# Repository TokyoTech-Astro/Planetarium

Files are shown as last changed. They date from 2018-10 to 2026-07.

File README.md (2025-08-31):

# ディレクトリ構成

planetarium: 回路データ \
planetarium<西暦>: 各年にデプロイされたシステム \
memo: メモ(モーターの型番や星座とプレートナンバーの対応などの基本情報) 

# Bluetoothオーディオの使い方

## スピーカーとの接続方法

bluetoothctlを使う

[コマンド一覧](https://qiita.com/noraworld/items/55c0cb1eb52cf8dccc12)

```
$ bluetoothctl
```

デバイスの電源オン

```
# power on
# agent on
```

スキャン

```
# scan on
# scan off
```

ペアリング（スキャンで得たアドレスを指定する）

```
# pair 30:21:B0:70:83:33
# trust
```

接続

```
# connect 30:21:B0:70:83:33
```

## 音声の確認

```
aplay /usr/share/sounds/alsa/*
```

```
yt-dlp "https://www.youtube.com/watch?v=j7CDb610Bg0" -f bestaudio -o - | mplayer - -novideo
```

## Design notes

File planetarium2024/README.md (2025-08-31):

# RaspberryPiの基本情報

pi-controller(球外のpi)とpi-starsphere(球内のpi)の2枚を使用。

pi-controllerがオーディオ、モータ、恒星、ウェブサーバを担当。\
pi-starphereが星座、一等星を担当。

ホスト名
- pi-controller.local
- pi-starsphere.local

ユーザ名: pi \
パスワード: raspberry

## wifiへの自動接続
記憶が怪しいがnmcliで設定してた気がする。軽く調べて`../memo_wifi.txt`に申し訳程度にまとめておいたのでそちらを参照。

## bluetoothスピーカーへの自動接続
`apiServerAudio/autoconnector.sh`をcrontabで定期的に実行。\
＊ちょっと動作が怪しいので改良が必用。前繋がらなかったときは一回ペアリングを解除してから再接続したら解決した。

`../README.md`に情報あり。

# 各ディレクトリの説明

## httpServer
- スマホで操作するためのウェブページのサーバ
- Next.js + Material-UI(MUI)
- pm2を使いラズパイ本体起動時に自動起動
- `http://pi-controller.local:3000`でアクセス可能
- pi-controllerで動作

## apiServerAudio
- 音声を再生するAPIを提供
- bluetoothスピーカーへの自動接続スクリプトも含まれている
- pi-controllerで動作
- `pi-controller.local:8001`で動作

## apiServerMotor
- モータを駆動するAPIを提供
- pi-controllerで動作
- `pi-controller.local:8000`で動作

## apiServerLED
- LEDのを制御するAPIを提供
- pi-controllerとpi-starsphere(球内のpi)の両方で全く同じコードが実行されている
- `pi-starsphere.local:8002`、`pi-controller.local:8002`で動作

# デプロイ方法

## 環境変数
LEDのピンアサインや番組構成を変更する場合はこれらのファイルを書き換える。
- `leds.json`
- `k2023.json`
- `httpServer/.env`

各サブディレクトリ内にこれらへのシンボリックリンクが配置されていて、プログラムではシンボリックリンクを参照している。
- `apiServerLED/leds.json`と`httpServer/src/leds.json`は`leds.json`へのシンボリックリンクである。
- `httpServer/src/k2023.json`は`k2023.json`へのシンボリックリンクである。
- `httpServer/.env`のシンボリックリンクはなくプログラムから直接参照されている。

## サーバー自動起動設定

### httpServer
pm2を使って自動起動 \
See also: `memo_pm2.txt` `https://zenn.dev/dokokade/articles/452b5376f9e260`

### apiServerLED, apiServerMotor
systemdを使ってラズパイ起動時にソフトも自動起動

### apiServerAudio
apiServerLEDやapiServerMotorと同じくsystemdを使っているが--userオプションが必用。

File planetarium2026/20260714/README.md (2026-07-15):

# プラネ統合制御システム 20260714

統括・モーター制御とライト制御の両方にXIAO ESP32C3を使用します。

- `firmware/coordinator`: PCとのUART、モーター直接制御、ライト基板とのESP-NOW通信
- `firmware/light_controller`: 一等星、恒星、星座1～8の出力と状態返信
- `pc_ui`: Windows操作UIとEXE
- `docs`: 配線、設定、通信仕様

従来の独立したモーター制御マイコンは廃止し、統括マイコンへ統合しました。統括・モーター基板とライト基板の2台構成です。

ESP32C3はシングルコアのため、USB CDC・ESP-NOW・JSON処理はFreeRTOS通信タスクで動作します。モーターのCLOCK生成はハードウェアタイマー割り込みへ分離しているため、通信処理中もステップパルス生成を継続します。

## ビルド

各有効プロジェクトのフォルダーで次を実行します。

```powershell
pio run
```

書き込み前に、`firmware/coordinator/platformio.ini` のモーター1回転ステップ数、マイクロステップ数、回転方向を実機に合わせてください。

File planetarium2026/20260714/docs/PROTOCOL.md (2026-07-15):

# 通信仕様

## PC ⇔ 統括 (USB UART, 115200 bps, UTF-8 JSON Lines)

PCから送る主コマンド:

```json
{"cmd":"set","seq":12,"motor":{"angle":30.0,"speed":4.0},"light":{"first":true,"stars":true,"patterns":[true,false,false,false,false,false,false,false]}}
{"cmd":"config","esp_interval_ms":10000,"retry_timeout_ms":500,"max_retries":5}
{"cmd":"ping"}
{"cmd":"motor_cal","action":"jog_cw","speed":2.0,"value":0}
{"cmd":"motor_cal","action":"move_relative","speed":2.0,"value":-5.0}
{"cmd":"motor_cal","action":"set_zero","speed":0,"value":0}
{"cmd":"motor_cal","action":"set_angle","speed":0,"value":12.5}
{"cmd":"motor_cal","action":"exit","speed":0,"value":0}
```

統括からは `hello`, `status`, `event`, `pong` を返信します。`status` は各子機の通信状態、最終通信時刻、実際に反映された値を含みます。

`motor_cal` のactionは `jog_cw`, `jog_ccw`, `stop`, `move_relative`, `set_zero`, `set_angle`, `exit` です。校正コマンド受信後はモーターへの通常周期設定を一時停止し、`exit` で速度0として通常制御へ戻します。ライトへの周期送信は校正中も継続します。

## ESP-NOW

`protocol.h` のpacked固定長構造体を使用します。全パケットにmagic、version、type、sequenceを持たせます。統括は設定変更時に即送信し、通常時も設定間隔ごとに再送します。子機ACKがタイムアウトした場合は最大5回再送し、その間を不安定、終了後を途絶と判定します。

モーター校正には `MOTOR_CAL` と `MotorCalPayload` を使用し、通常のモーターACKで校正後の論理角度と速度を返信します。

固定MAC（ローカル管理アドレス）:

- 統括: `02:50:4C:41:4E:01`
- ライト: `02:50:4C:41:4E:02`
- モーター: `02:50:4C:41:4E:03`

## 現行プロトコル（Version 3）

- `AckPayload.angleDeg` は目標角度ではなく、統括・モーターマイコンが管理している実機の現在角度です。通常時は `0.0°以上360.0°未満` に正規化され、UIの「目標角度」行にある「実機現在値」へ表示されます。
- 目標角度 `999` は時計回り、`-999` は反時計回りの連続回転コマンドです。どちらも物理角度ではありません。連続回転中もACKの `angleDeg` は現在角度を返します。
- `AckPayload.uptimeMs` は各マイコンの起動後経過時間です。
- モーター校正中のUART `status.actual.motor.speed` は符号付きです。正は時計回り、負は反時計回り、0は停止を示します（ESP-NOWの構造体形式は変更しません）。
- 校正中の動作種別はUART `status.actual.motor.motion` で通知します。値は `jog_cw`（時計回り連続回転）、`jog_ccw`（反時計回り連続回転）、`relative`（相対角度移動）、`stopped`（停止）です。
- `status.actual.motor.target_angle` は位置移動の論理目標角度（0°以上360°未満）です。UIは相対角度移動中にこの値を表示します。
- `LightPayload.heartbeatTimeoutMs` はライト制御基板が通信切断と判断する時間です。統括側はESP-NOW定期送信間隔からこの値を算出して送信します。
- `LightPayload.fade` は、音声再生中にタイムラインが自然進行して設定値が変化した場合だけ `1` になります。ライト基板は恒星・一等星・星座出力を約1.2秒でフェードします。手動操作、シーク、再接続、即時送信では `0` となり即時反映します。

## 緊急停止

- PCから `{"cmd":"emergency_stop"}` を受けると、統括・モーター基板は緊急停止状態をラッチします。
- モーターの連続回転、位置移動、校正ジョグを直ちに停止し、回転速度を0にします。
- 一等星、恒星、星座1～8をすべてOFFとしてライト基板へ即時送信します。
- 緊急停止中の通常設定およびモーター校正指令は拒否されます。
- `{"cmd":"emergency_stop_release"}` を受けるまで、UARTの定期設定やタイムライン指令では解除されません。
- `status.emergency_stop` で現在のラッチ状態をUIへ通知します。
- ライト制御基板は有効な `LIGHT_SET` の最終受信から `heartbeatTimeoutMs` を超えると切断状態とし、D6の状態LEDを高速点滅します。正常時はゆっくり点滅します。
- 構造体変更によりVersion 3と旧Versionには互換性がありません。統括・モーター側とライト側を同じ版へ書き換えてください。

Wi-Fiチャネルは1に固定しています。

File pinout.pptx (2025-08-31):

## RaspberryPi

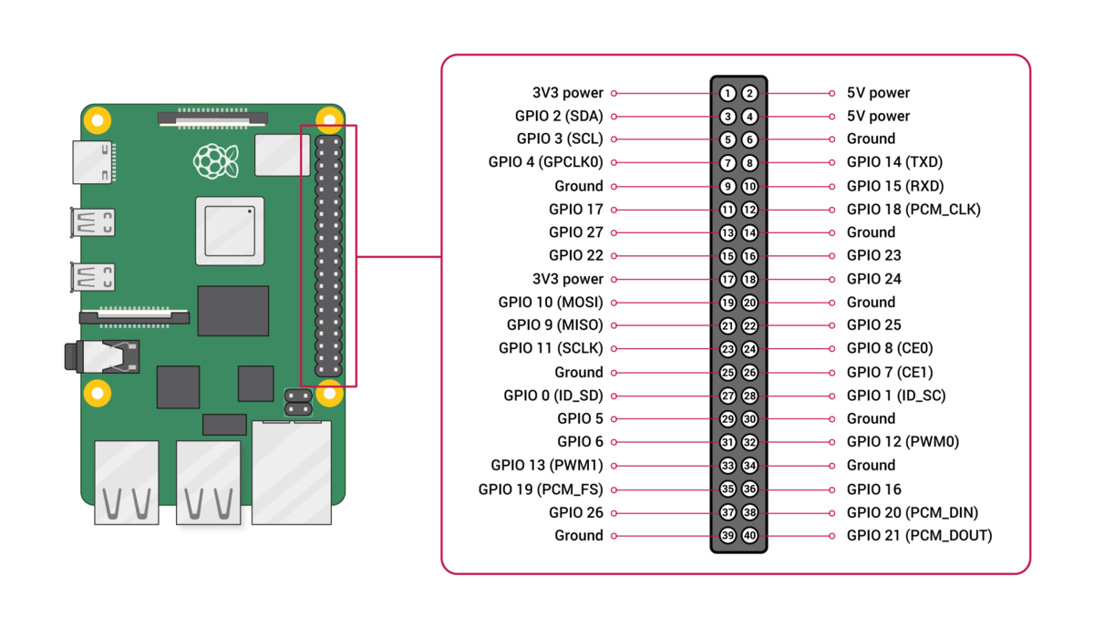
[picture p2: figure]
Raspberry PiのGPIOピン配置を確認する - BioErrorLog Tech Blog

緑文字＝モタドラ信号

| 1 | 2
| 3 | 4
| 5 | 6 | GND
Vdd | 7 | 8 | TX
GND | 9 | 10 | RX
sleep_ref | 11 | 12
cw_ccw | 13 | 14
clk | 15 | 16
| 17 | 18 | 一等星
恒星 | 19 | 20 | GND
| 21 | 22
| 23 | 24
| 25 | 26
| 27 | 28
| 29 | 30
| 31 | 32
| 33 | 34
| 35 | 36
| 37 | 38
| 39 | 40

Vdd

sleep/ref

cw_ccw

clk

星座

一等星

## 星座基板

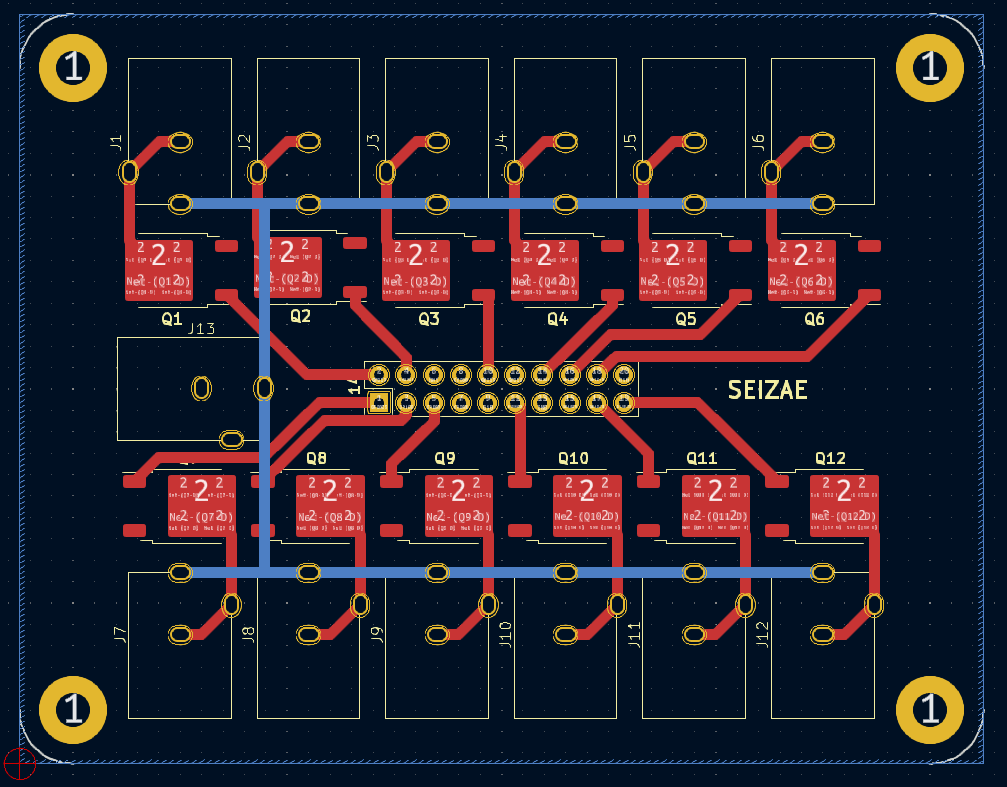
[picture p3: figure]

GPIO09

GPIO11

GPIO05

GPIO13

GPIO19

GPIO26

星座名 | GPIO (ラズパイ)
こぐま | 19
ぺがすす | 11
オリオン | 26
こいぬ | 13
さそり | 9
いて | 21

GPIO25

GPIO08

GPIO07

GPIO12

GPIO20

GPIO21

## モタドラ(SLA7078MPRT)

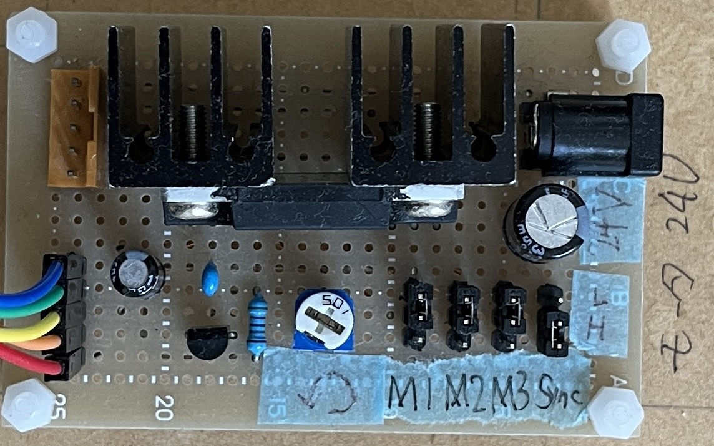
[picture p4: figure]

cw_ccw

clk

GND

sleep/ref

Vdd

参照電圧
(ccwに回転で上昇)

モードセレクト

IC: https://akizukidenshi.com/catalog/g/g108015/

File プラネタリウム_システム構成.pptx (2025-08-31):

## システム構成(2024)

RaspberryPi(pi-contoller)

球外

球内

RaspberryPi(pi-starsphere)

LED API

Webサーバ

LED API

ルータ

Audio API

モータ API

モータ基板
(24V駆動)

恒星基板
(24V駆動)

一等星基板
(5V駆動)

星座基板
(5V駆動)

※ラズパイから各APIへはhttpリクエストでアクセス

## システム構成(2025)

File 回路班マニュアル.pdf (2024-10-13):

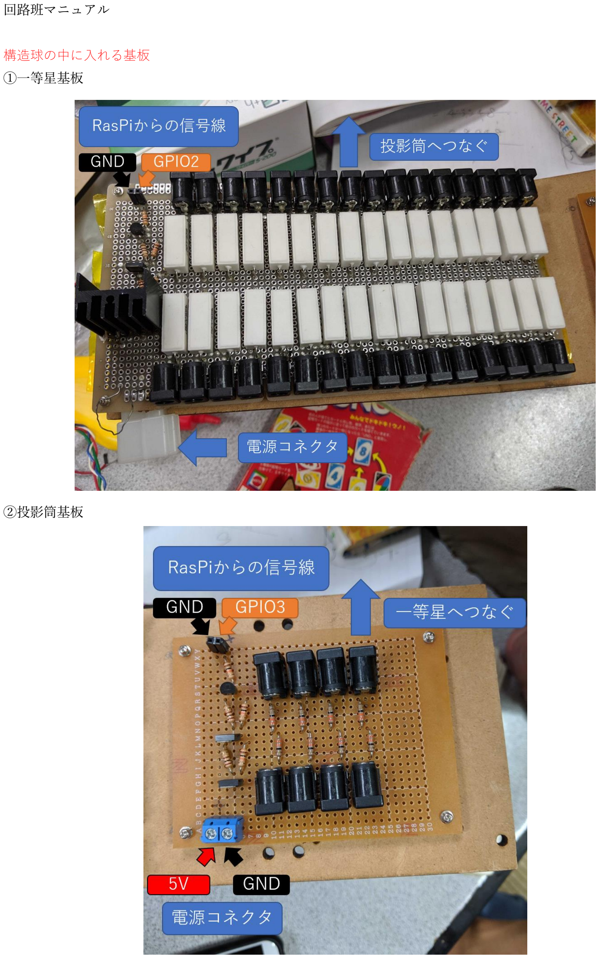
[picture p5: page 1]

回路班マニュアル

構造球の中に入れる基板
①一等星基板

②投影筒基板

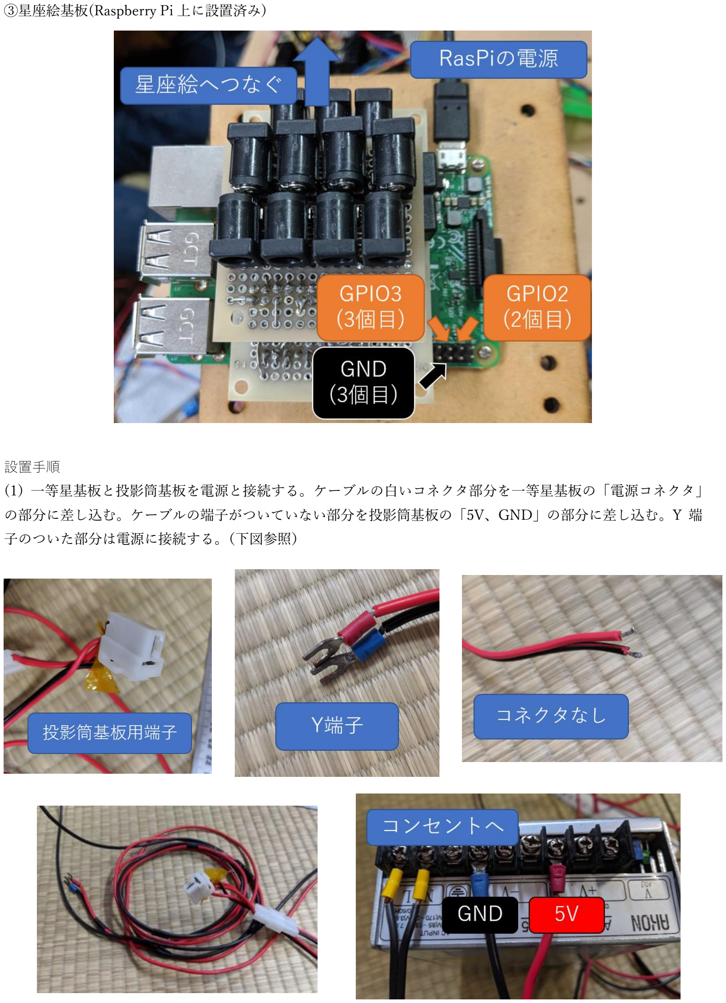
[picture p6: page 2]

③星座絵基板(Raspberry Pi 上に設置済み)

設置手順
(1) 一等星基板と投影筒基板を電源と接続する。ケーブルの白いコネクタ部分を一等星基板の「電源コネクタ」 の部分に差し込む。ケーブルの端子がついていない部分を投影筒基板の「5V、GND」の部分に差し込む。Y 端 子のついた部分は電源に接続する。（下図参照）

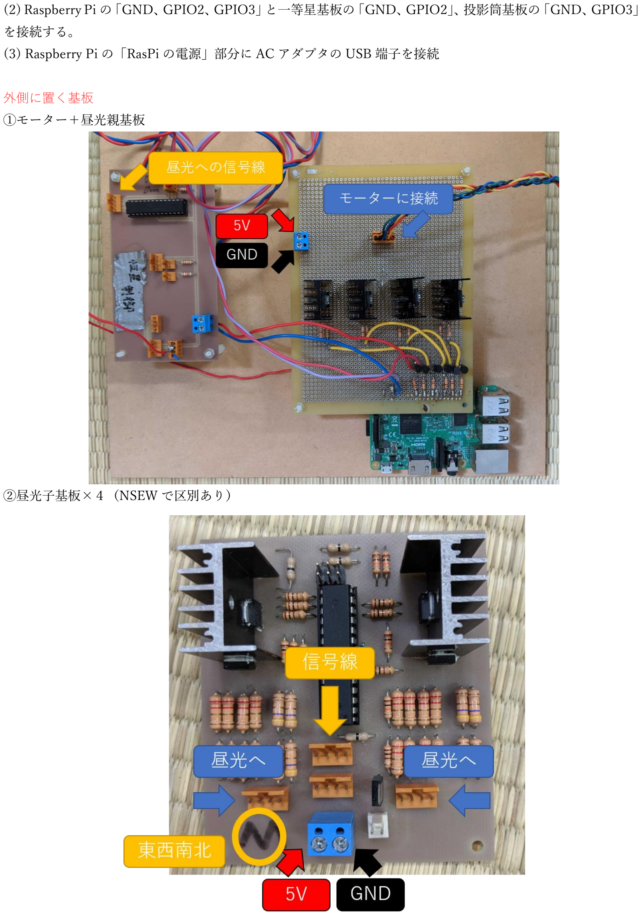
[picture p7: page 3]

(2) Raspberry Pi の「GND、GPIO2、GPIO3」と一等星基板の「GND、GPIO2」、投影筒基板の「GND、GPIO3」 を接続する。
(3) Raspberry Pi の「RasPi の電源」部分に AC アダプタの USB 端子を接続

外側に置く基板
①モーター＋昼光親基板

②昼光子基板×４（NSEW で区別あり）

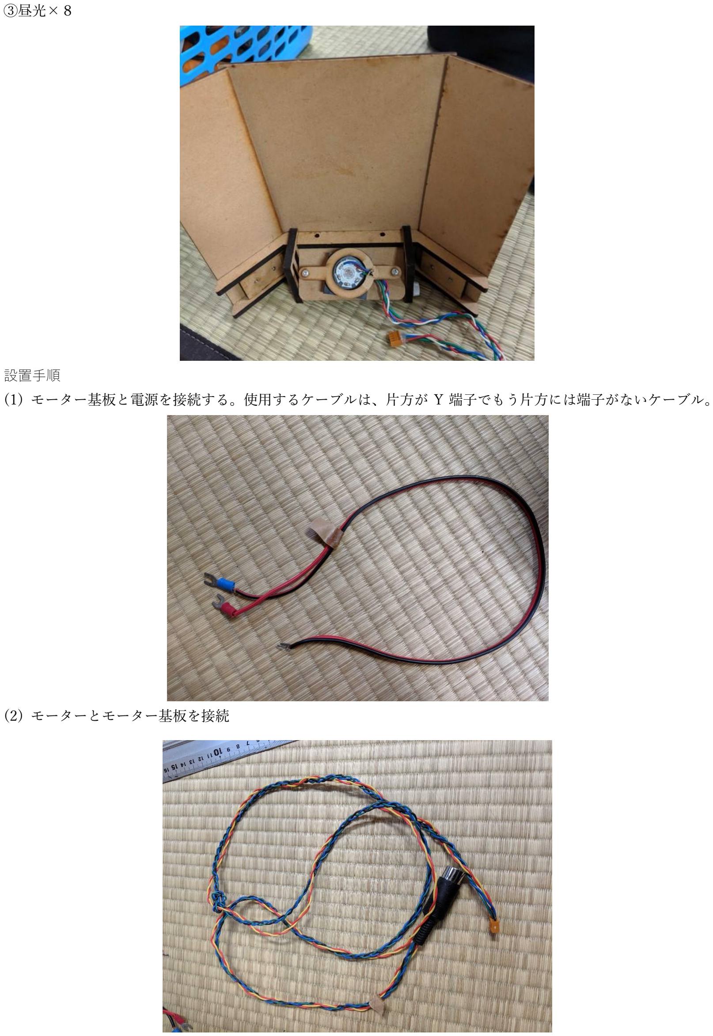
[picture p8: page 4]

③昼光×８

設置手順
(1) モーター基板と電源を接続する。使用するケーブルは、片方が Y 端子でもう片方には端子がないケーブル。
(2) モーターとモーター基板を接続

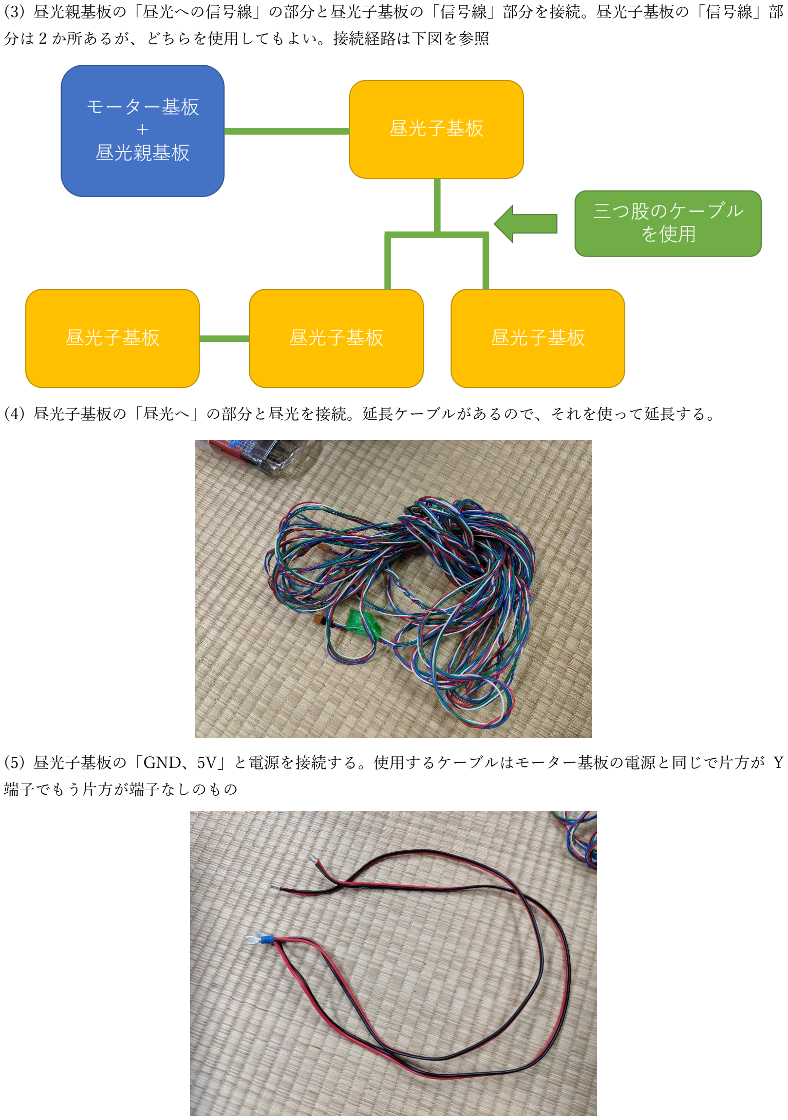
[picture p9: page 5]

(3) 昼光親基板の「昼光への信号線」の部分と昼光子基板の「信号線」部分を接続。昼光子基板の「信号線」部 分は 2 か所あるが、どちらを使用してもよい。接続経路は下図を参照
(4) 昼光子基板の「昼光へ」の部分と昼光を接続。延長ケーブルがあるので、それを使って延長する。
(5) 昼光子基板の「GND、5V」と電源を接続する。使用するケーブルはモーター基板の電源と同じで片方が Y 端子でもう片方が端子なしのもの

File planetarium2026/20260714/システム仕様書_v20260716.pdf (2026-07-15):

# プラネタリウム統合制御 システム仕様書

## PC UI・ステッピングモーター・ライト制御・通信・安全機能

対象システム

統括＋モーター基板：Seeed Studio XIAO ESP32C3 ライト制御基板：Seeed Studio XIAO ESP32C3 PC通信：USB CDC / UART 115200 bps 基板間通信：ESP-NOW（Wi-Fi Channel 1）

文書版：v20260716

対象フォルダ：planetarium2026 / 20260714

TokyoTech-Astro Planetarium Project

1. システム概要 | 全体構成と役割

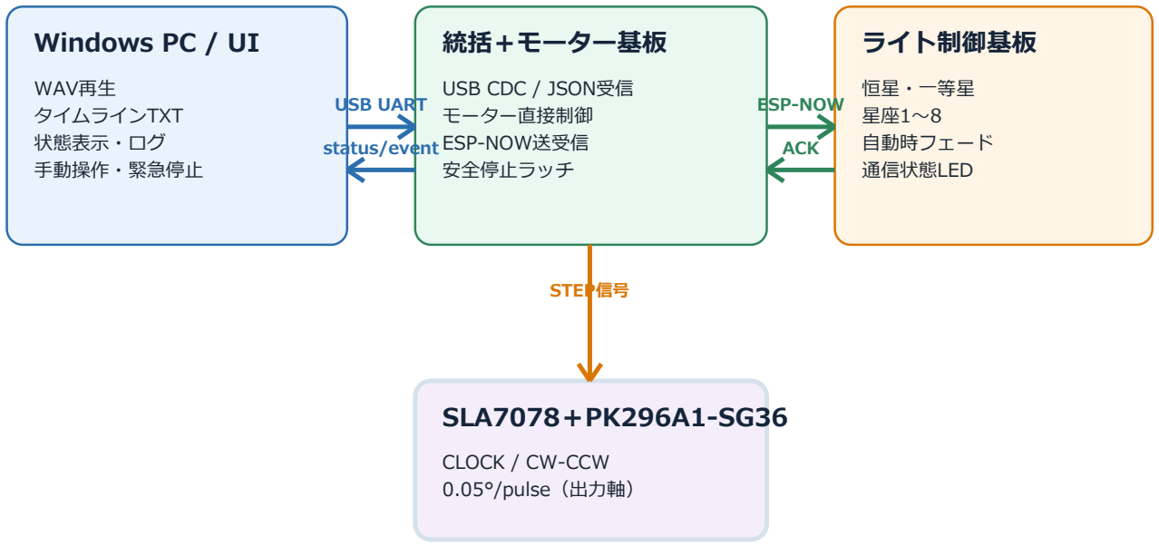
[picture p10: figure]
Windows PC / UI; WAV再生 タイムラインTXT 状態表示・ログ 手動操作・緊急停止; 統括＋モーター基板; USB CDC / JSON受信 モーター直接制御 ESP-NOW送受信 安全停止ラッチ; ライト制御基板; 恒星・一等星 星座1～8 自動時フェード 通信状態LED; USB UART; ESP-NOW; status/event; ACK; SLA7078＋PK296A1-SG36; CLOCK / CW-CCW 0.05°/pulse（出力軸）; STEP信号

プラネタリウム統合制御システム仕様書 v20260716 | 1

目的

音声ファイルの再生位置に同期して、ステッピングモーターの角度・速度と、恒星、一等星、星座1～8の点灯状態を自 動制御する。PC上のUIは状態監視、手動上書き、原点設定、緊急停止、ログ記録を担当する。

## 構成図

## 設計上の基本方針

モーターのSTEPパルス生成は40 kHzハードウェアタイマー割り込みへ分離し、通信処理の遅延から保護する。 PC通信が3秒途絶すると、統括基板単独でモーターを停止する。 再起動後は原点未設定とし、0°設定または現在角度設定まで通常移動を禁止する。 緊急停止は統括基板側でラッチし、明示的な解除まで通常指令と校正指令を拒否する。

2. PC UIとタイムライン制御 | 音声同期・操作・監視

## タイムラインの動作

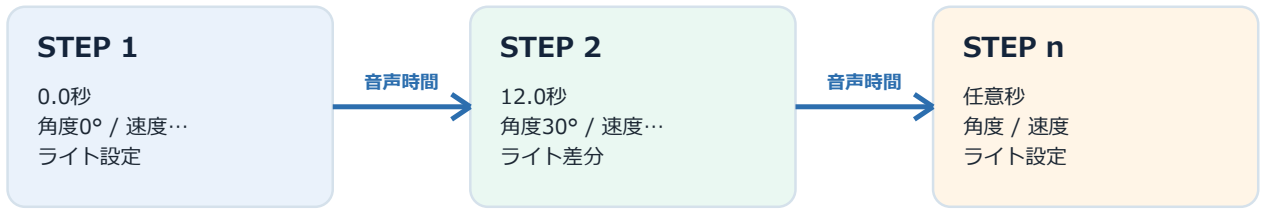
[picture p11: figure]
STEP 1; 0.0秒 角度0° / 速度… ライト設定; STEP 2; 12.0秒 角度30° / 速度… ライト差分; STEP n; 任意秒 角度 / 速度 ライト設定; 音声時間

再生位置がSTEP時刻を通過すると、そのSTEPの全設定値をUARTで即時送信する。設定に変化がない場合は送信を省略 し、変化がなくても既定10秒ごとに全設定を再送する。音楽再生中の自然なSTEP進行だけ、ライト指令の fade=true と なる。

## UIが提供する主な機能

区分 | 機能
音声 | WAV選択、再生・停止、シーク、倍率変更（ピッチ維持）、最初から再生
STEP | 全STEP一覧、現在STEP強調、前後移動、ダブルクリック移動、TXT編集
監視 | UART / ESP-NOW状態、最終通信、起動時間、要求値と実機値、ログ
手動 | 角度・速度・各ライトの上書き、現在値の即時送信
保守 | 0°設定、現在角度設定、ジョグ、相対角度移動
安全 | 緊急停止、赤色バナー、解除確認、通信途絶時の不明値表示

## 設定値の表示規則

ONは緑、OFFは赤。通信できないときの実機値には「?」を付け、確定値と区別する。 要求値と実機値が一致しない系統は、反映インジケータを赤く点滅させる。 手動上書き中の系統は背景色を変え、自動タイムラインより優先されていることを示す。

3. PC - 統括基板間通信 | USB CDC / UART / JSON Lines

## 物理・データ仕様

項目 | 仕様
接続 | XIAO ESP32C3 USB Type-C / USB CDC
通信速度 | 115200 bps
形式 | UTF-8 JSON、1メッセージ1行（改行終端）
定期送信 | 全設定：既定10秒、ping：1秒
安全監視 | 有効パケットを3秒受信しない場合、モーター強制停止

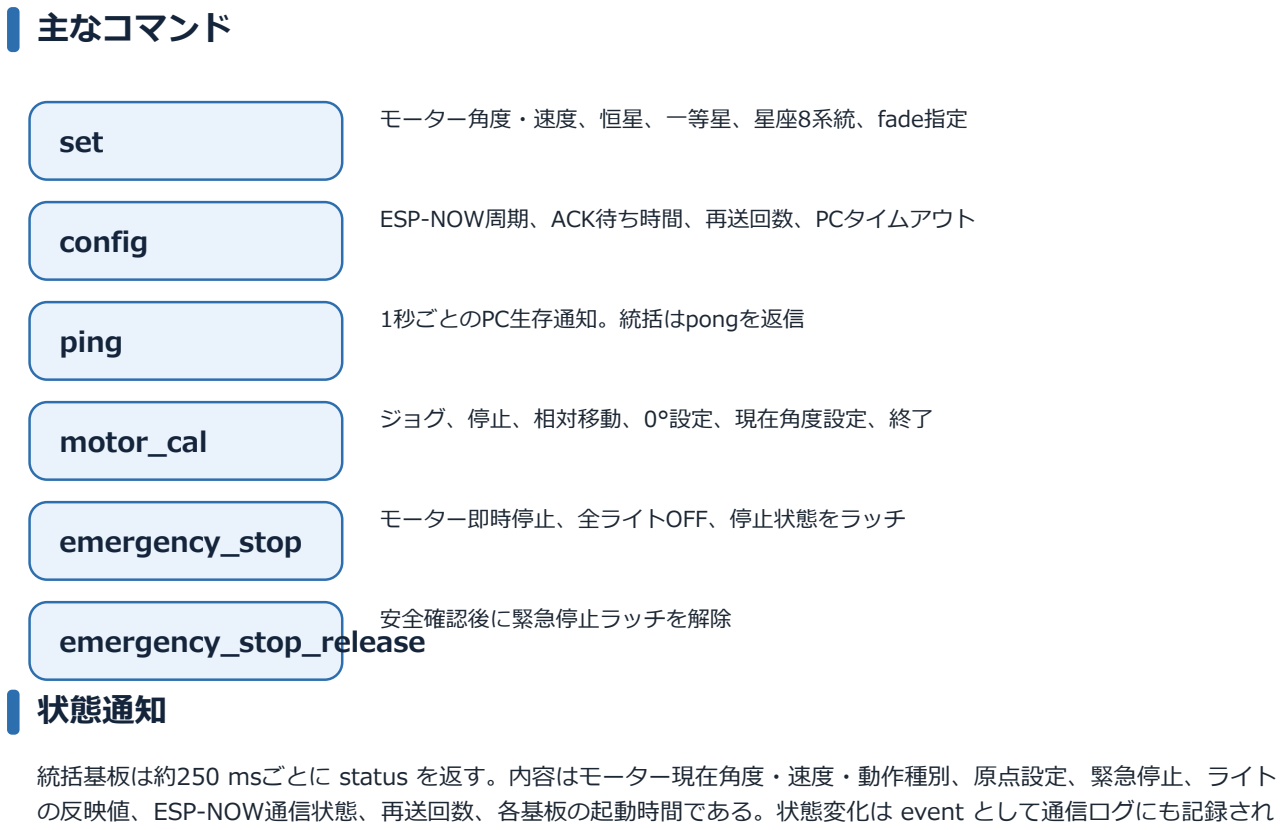
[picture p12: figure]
主なコマンド; set; モーター角度・速度、恒星、一等星、星座8系統、fade指定; config; ESP-NOW周期、ACK待ち時間、再送回数、PCタイムアウト; ping; 1秒ごとのPC生存通知。統括はpongを返信; motor_cal; ジョグ、停止、相対移動、0°設定、現在角度設定、終了; emergency_stop; モーター即時停止、全ライトOFF、停止状態をラッチ; emergency_stop_release; 安全確認後に緊急停止ラッチを解除; 状態通知; 統括基板は約250 msごとに status を返す。内容はモーター現在角度・速度・動作種別、原点設定、緊急停止、ライト の反映値、ESP-NOW通信状態、再送回数、各基板の起動時間である。状態変化は event として通信ログにも記録され

る。

4. ステッピングモーター制御 | 統括基板内蔵・タイマー分離

## 対象とパルス換算

PK296A1-SG36

2相ステッピングモーター
基本角1.8°、減速比36:1
出力軸：7,200 pulse/rev = 0.05°/pulse

制御上限

角度管理：0.0°以上360.0°未満
設定最大速度：300°/s
通常は実機に適した低速で運用

## 制御経路

ESP32C3はシングルコアだが、モーターCLOCK生成をハードウェアタイマー割り込みへ分離している。UART、JSON 、ESP-NOWの処理時間に左右されず、割り込みが継続してSTEPパルスを生成する。共有値の変更はクリティカル区間 で行う。

## 角度・原点・連続回転

通常角度は0°以上360°未満に正規化し、現在位置から最短方向で目標へ移動する。 目標角度999は時計回り、-999は反時計回りの連続回転コマンドであり、物理角度ではない。 再起動すると原点未設定となり、通常移動と±999を拒否する。ライト設定は先に復元できる。 0°設定または現在角度設定後に通常移動を許可する。校正画面の初期速度は0°/s。

## 主なGPIO

端子 | 用途
D0 | MO
D1/D8/D7 | M2 / M1 / M3
D2 | CLOCK
D3 | CW/CCW
D4 | FLAG
D5/D6 | SYNC / RESET
D9 | Driver Sleep
D10 | Status LED

5. 統括 - ライト基板間通信 | ESP-NOW / 固定MAC / ACK再送

## 無線設定

項目 | 統括＋モーター | ライト
固定MAC | 02:50:4C:41:4E:01 | 02:50:4C:41:4E:02
Wi-Fi Channel | 1 | 1
暗号化 | なし | なし
プロトコル | Packed struct / Version 3 | Packed struct / Version 3

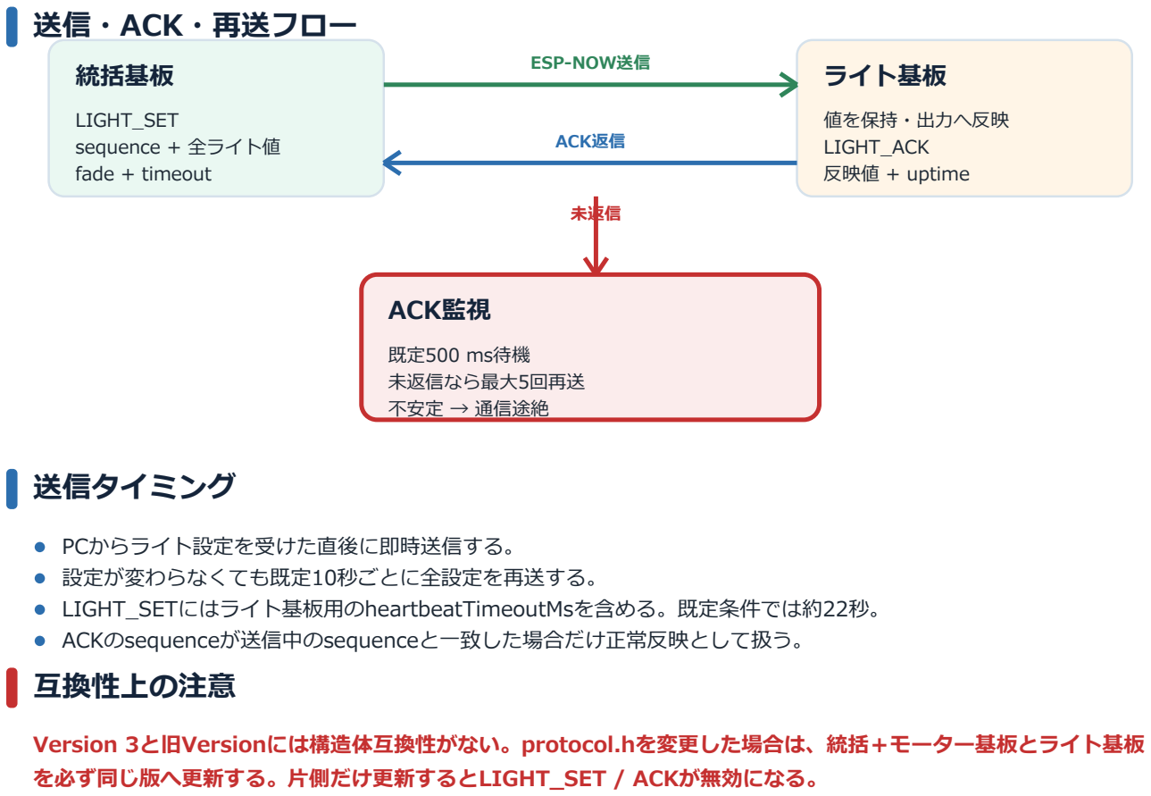
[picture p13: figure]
送信・ACK・再送フロー; 統括基板; LIGHT_SET sequence + 全ライト値 fade + timeout; ライト基板; 値を保持・出力へ反映 LIGHT_ACK 反映値 + uptime; ESP-NOW送信; ACK返信; ACK監視; 既定500 ms待機 未返信なら最大5回再送 不安定 → 通信途絶; 未返信; 送信タイミング; PCからライト設定を受けた直後に即時送信する。 設定が変わらなくても既定10秒ごとに全設定を再送する。 LIGHT_SETにはライト基板用のheartbeatTimeoutMsを含める。既定条件では約22秒。 ACKのsequenceが送信中のsequenceと一致した場合だけ正常反映として扱う。 互換性上の注意; Version 3と旧Versionには構造体互換性がない。protocol.hを変更した場合は、統括＋モーター基板とライト基板; を必ず同じ版へ更新する。片側だけ更新するとLIGHT_SET / ACKが無効になる。

## 出力割当

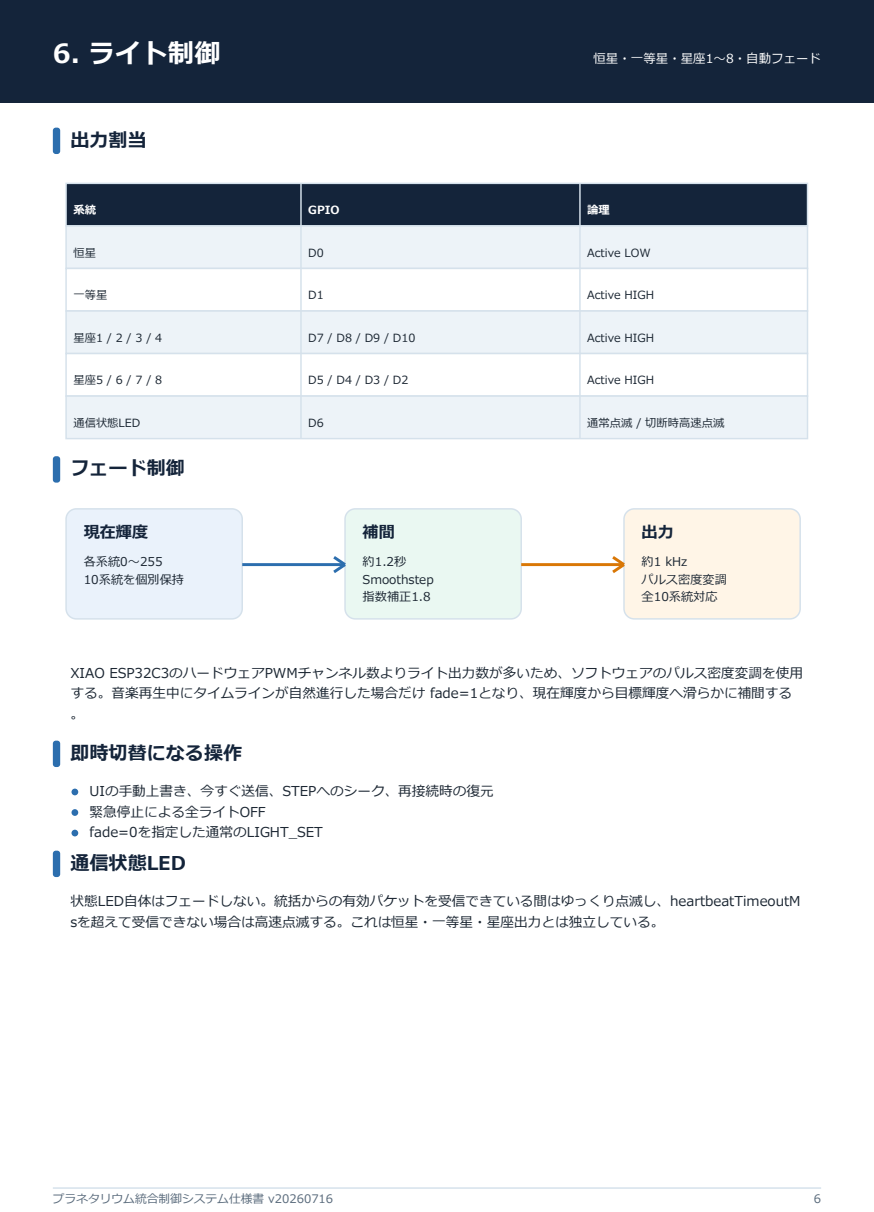
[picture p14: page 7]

XIAO ESP32C3のハードウェアPWMチャンネル数よりライト出力数が多いため、ソフトウェアのパルス密度変調を使用
する。音楽再生中にタイムラインが自然進行した場合だけ fade=1となり、現在輝度から目標輝度へ滑らかに補間する

状態LED自体はフェードしない。統括からの有効パケットを受信できている間はゆっくり点滅し、heartbeatTimeoutM
sを超えて受信できない場合は高速点滅する。これは恒星・一等星・星座出力とは独立している。

7. 安全機能と状態遷移 | 再起動・通信途絶・緊急停止

## モーター許可状態

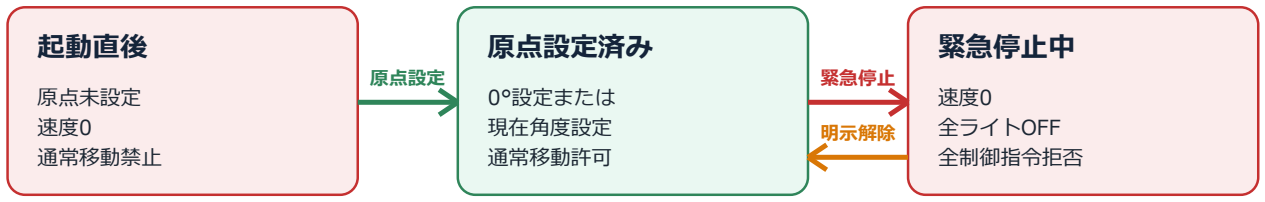
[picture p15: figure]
起動直後; 原点未設定 速度0 通常移動禁止; 原点設定済み; 0°設定または 現在角度設定 通常移動許可; 緊急停止中; 速度0 全ライトOFF 全制御指令拒否; 原点設定; 緊急停止; 明示解除

## PC通信途絶時

USB抜去、UIフリーズ、PC停止のいずれでも、統括基板が独立してモーター制御値をクリティカル区間内で停止値へ変 更する。PCが復帰した場合はeventを通知し、新しい有効指令から制御を再開する。

## 緊急停止フロー

### 1 UIの赤い緊急停止ボタンを押す

### 2 統括基板がラッチし、モーター即時停止・ライト全OFF

### 3 通常set、校正、タイムライン、定期送信を拒否

### 4 UIへ赤い緊急停止中バナーを表示

### 5 安全確認ダイアログ後、解除専用コマンドを送信

### 6 解除後に現在のUI設定を再送信

8. 起動・運用・保守 | 操作者と保守担当者の確認事項

## 標準起動手順

1 24Vを入れる前に、モーター基板のUSB Type-CをPCへ接続する。

### 2 モーター基板とライト基板へ24V電源を投入する。

### 3 UIを起動し、COMポートを選択してUART接続を押す。

### 4 PC－統括、統括－ライトの通信表示が正常であることを確認する。

### 5 指示設定TXTと対応するWAVを選択する。

### 6 Bluetoothスピーカーへ接続し、UIの出力先表示を確認する。

### 7 音声停止中にモーター0°位置を設定する。

### 8 自動変更ON、安全確認済みを確認して再生する。

## 保守時の重要事項

protocol.hを変更したときは、統括基板とライト基板の両方を同じVersionへ更新する。 モーター基板を書き換えた後、または再起動後は、必ず原点設定を行う。 異常音、振動、予期しない回転がある場合は緊急停止し、必要なら24Vを切る。 通常の操作者は操作者用フォルダだけを使用し、firmwareやpc_uiを変更しない。

## 関連ファイル

firmware/coordinator：統括＋モーター制御 firmware/light_controller：ライト制御 firmware/common/protocol.h：ESP-NOW共通構造体 pc_ui/app.py：Windows UI
docs/PROTOCOL.md：通信仕様
UIアプリの使用手順.txt：操作者向け詳細手順

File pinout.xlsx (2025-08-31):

 | 1 | 2 |  | 星座名 | pin num. (ラズパイ)
 | 3 | 4 |  | こぐま | 19
 | 5 | 6 | GND | ぺがすす | 11
Vdd | 7 | 8 | TX | オリオン | 26
GND | 9 | 10 | RX | こいぬ | 13
sleep_ref | 11 | 12 |  | さそり | 9
cw_ccw | 13 | 14 |  | いて | 21
clk | 15 | 16
 | 17 | 18 | 一等星
恒星 | 19 | 20 | GND
 | 21 | 22
 | 23 | 24
 | 25 | 26
 | 27 | 28
 | 29 | 30
 | 31 | 32
 | 33 | 34
 | 35 | 36
 | 37 | 38
 | 39 | 40

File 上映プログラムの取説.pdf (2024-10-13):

## 工大祭 2019 上映プログラムの取説

制作班チーフ 小池

1 | 事前準備
必要なソフト： | rlogin http://nanno.dip.jp/softlib/program/rlogin_x64.zip
netenum5 https://www.e-realize.com/netenum20191004.zip まずは上記の URL からダウンロードし、適宜 zip を展開しておきます。
2 | 上映の準備
2.1 | rlogin の設定
Wi-fi ルーター(Buffalo-G-203D)とラズベリーパイ 2 台を電源につなぎ起動します。PC をルーター に接続します。rlogin を起動し、左上のファイル→サーバーに接続→新規 と進みます。

ホスト名に pi-starsphere.local
ログインユーザー名に pi
パスワードに raspberry
と入力し保存します。

もう一度新規から画像の画面を開き、ホスト名を pi-controller.local に変え、ユーザー名・パスワードをその まま入力します。
入力ができたら、接続する機器を選んで接続します。こ

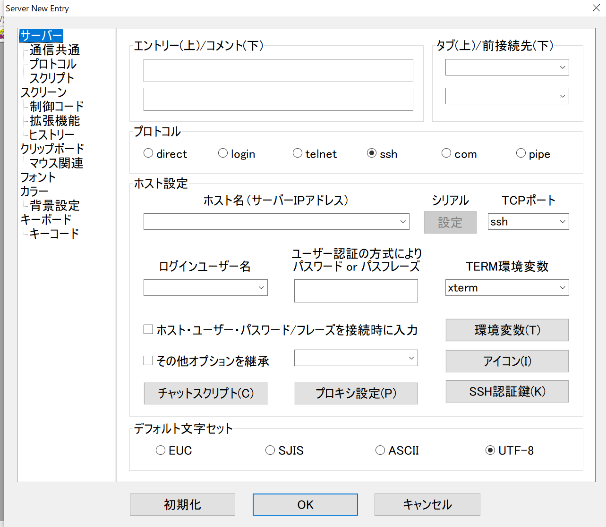
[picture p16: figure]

こで、エラーが発生した場合は 2.2 に進んでください。
2.2 2.1 でエラーがでたら NeteNum5 を起動します。左上の検索→検索設定と進み、設定はいじらず検索 します。ベンダー名に Raspberry Pi と出たら成功です(出なかったらもう一度やると出るようになる ことが多いです)
rlogin の設定画面で、ホスト名を～.local から NeteNum5 で表示された Ip アドレスに書き換えて再 度接続します。
(これでつながらなかったら終わり)
2.3 Rloin では 2 台のラズベリーパイをそれぞれつないでください。(rlogin を起動した画面で、ヘルプの 右下にある盾に分かれそうなボタンを押しましょう)
うまくいくとこんな感じになります。これでラズベリーパイを PC から動かせるようになりました (ssh 接続)

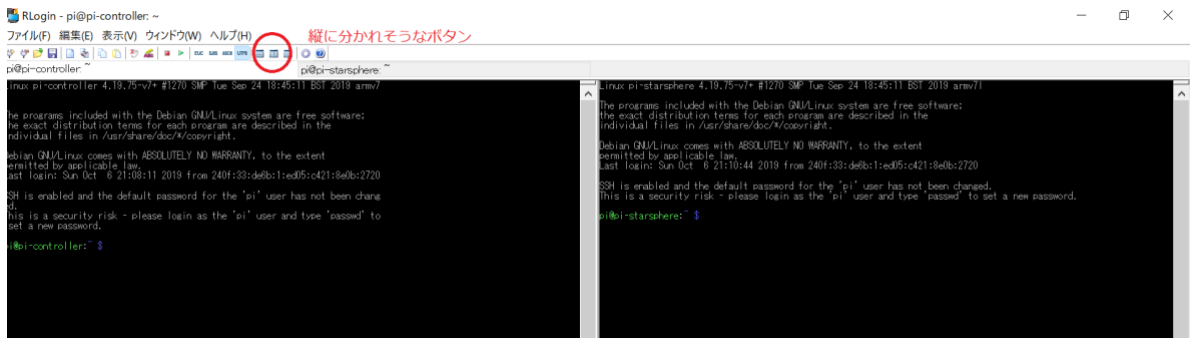
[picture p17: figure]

3 | ラズベリーパイの操作
3.1 | よく使うコマンドとか
cd (folder 名) | 指定したディレクトリに移動します。cd ..で一つ上に行けます。
ls | 現在のディレクトリ直下にあるファイルを一覧で見れます。
mkdir (名前) | 現在のディレクトリの直下に新しくフォルダを作ります。
nano (file 名) | ファイルを見て編集できます。
python3 (file 名)python のコードを実行します。
sh (file 名) | .sh のシェルスクリプトを実行します。
sudo reboot | 再起動します。
3.2 | 上映の実行の仕方
3.2.1 pi-starsphere(構造球側)で sh autorun.sh を実行します。 3.2.2 pi-controller(モーター側)で sh autorun.sh を実行します。 3.2.3 socket 通信が成功した場合はこんなのが出ます。

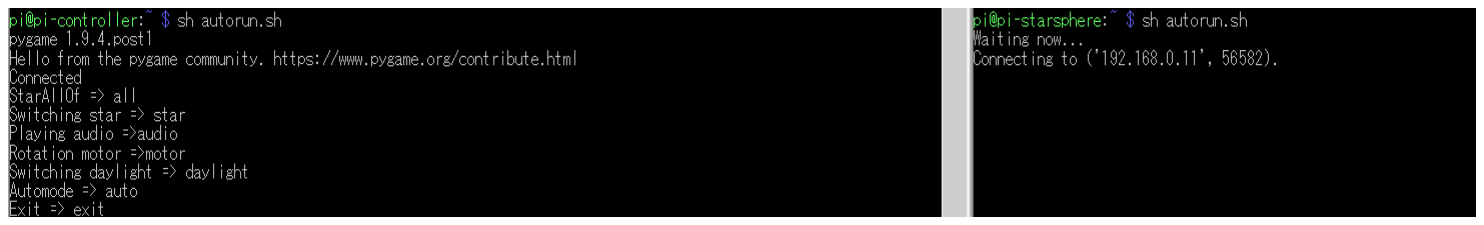
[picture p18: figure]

3.2.4 3 でエラーが出た場合は pi-starsphere のほうを再起動(sudo reboot)して、再度 pi-starsphere→ pi-controller の順で sh autorun.sh を実行します。
3.2.5 上映の時に使うのは Automode なので、pi-controller 側で auto と入力すると、上映が開始しま す。
3.2.6 終わると自動的に最初の画面に戻るので、次 auto と入力すれば ok です。
4 | バグったとき
4.1 | プログラムがやばそうな動きをしている
Ctrl + C で止めましょう。注意：必ず pi-controller のほうで行います。
4.2 モーターが回らない
3.2.3 の画像で、motor と入力します。その後 2 回数字が聞かれるので、0.04 と 200(または-200)と 入力すればモーターのテストができます。
4.3 星がつかない
3.2.3 の画像で star と入力します。そうすると on/off したい星と数字(または文字)の対応表が出るの で、目的の数字を入力します。この時、例えば 16 はこいぬ座の星座絵ですが、-16 とするとこいぬ 座を消すことができます。テストが終わったら exit と入力すれば先ほどの場面にもどります。 4.4 昼光がつかない
おなじみの方法で daylight と入力すると、on/off の選択肢が出るので好きなほうを入力してくださ い。
4.5 音が鳴らない
audio と入力してならなかったらスピーカーとかが原因です。
4.6 ラズパイが起動しない
終わりです、ごみを(ラズパイ)投げて本日の上映は終了です、と宣言しましょう。

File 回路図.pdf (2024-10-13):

## 天文る升

## r,xed stars)

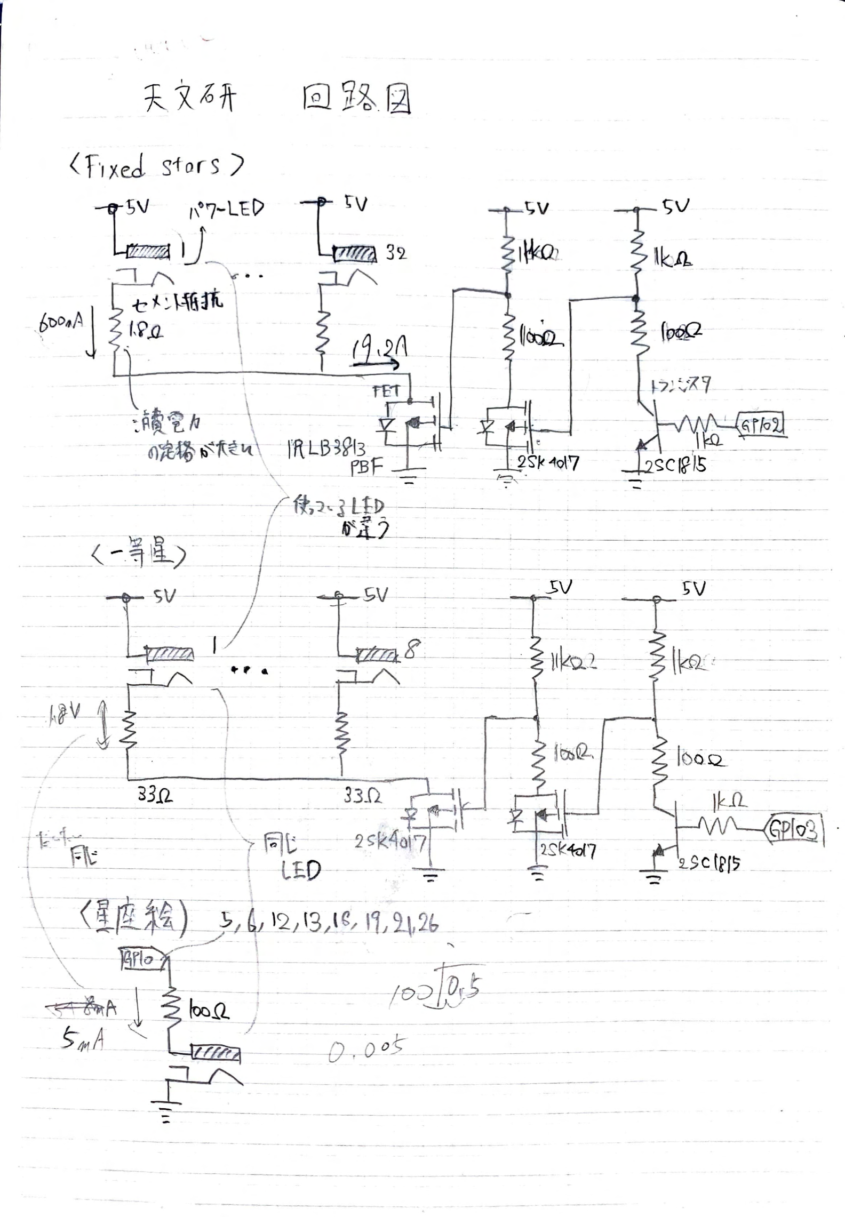
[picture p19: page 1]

- I•

# 1 7-L'ECl

ヘ
=-i_rヽ

~』砂；ン＼｀．．

## 回認旦

二鈴

佃和

心雌稔 ぶ紅＼1-t | !'ft.LB痢F.Bf _ | k-4o¥'/

I

r | ー | ・
1rs
ft1J ...l LfD | ――--――-
—- | ＿＿ ＿＿ーニ一ロ― ―
J | Tーロニ立~ ーニ _:_-~
｀口・・ r

_., . 一ヽ

## ―_ー印恥

lcQ | - ・一
、 | .
33立 | | | 3_Q
-、・,
; ・; ・ヤー—- -- • ー | ・ 極 | ~, 同 | 2s:-k401
-I -—~- -- -~- Lf. | --=:=--

（一

## c trr~ _ _

＼汀直釦三ぶ21訊 | 11,汎21, | ―

# 三三:~ {? , ° i;iと

三ゴ＼ — ---- -、一

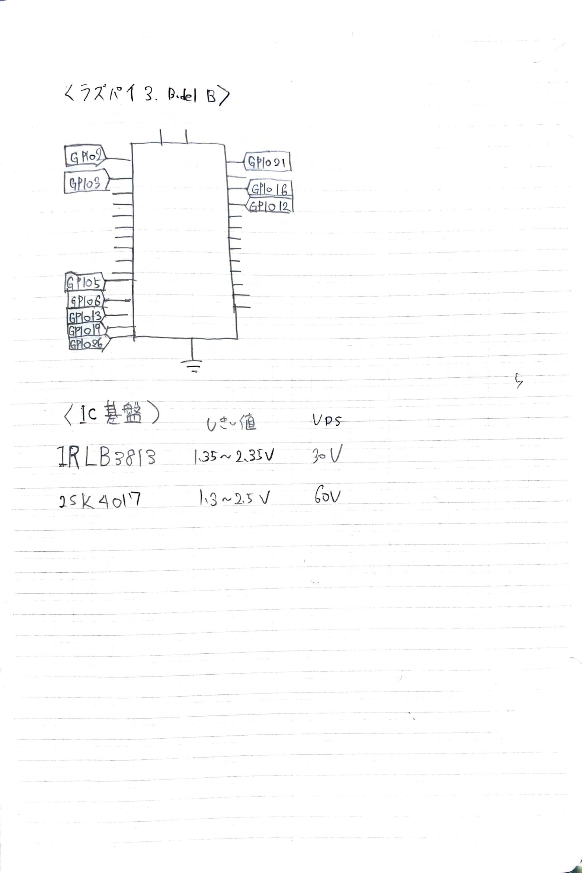
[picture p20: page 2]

くラズ（＼゜ 1'l(i、Jel
日、

←

## 甚磐〉 い!v〈直

- --― 仁 ―--

— V-P-5- -~- - ------ --- —
lRLB霜応 、3;-"" 、3S¥) ]。リ

_ 1~k L¥ o ¥'l ¥3 ~2S v I :>

I

人

## 応尤立

年）

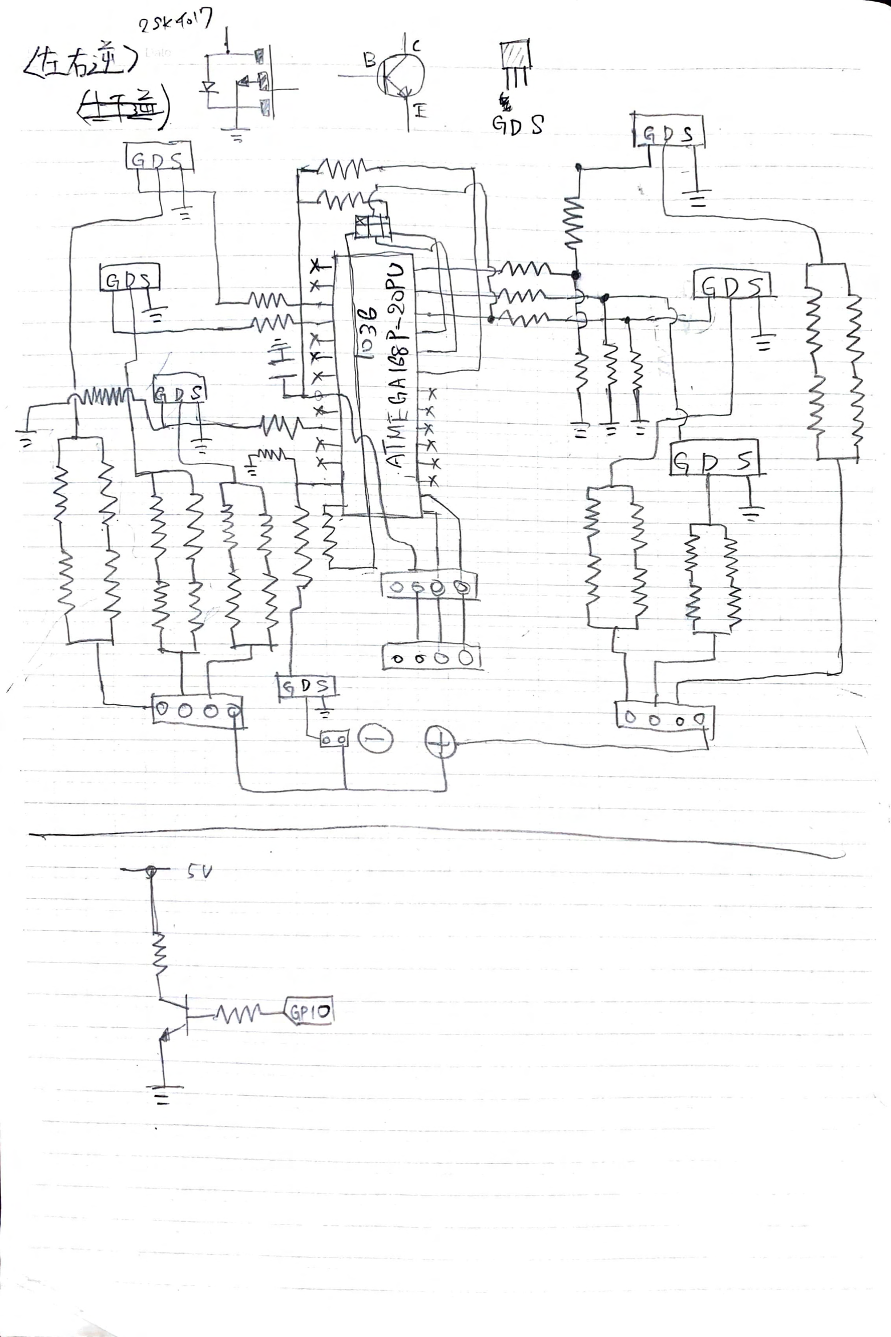
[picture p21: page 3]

s

開
ぷ

~:

／
‘ ＼、

r-v

ぃ憂

一

## （昼も芦的 ｀

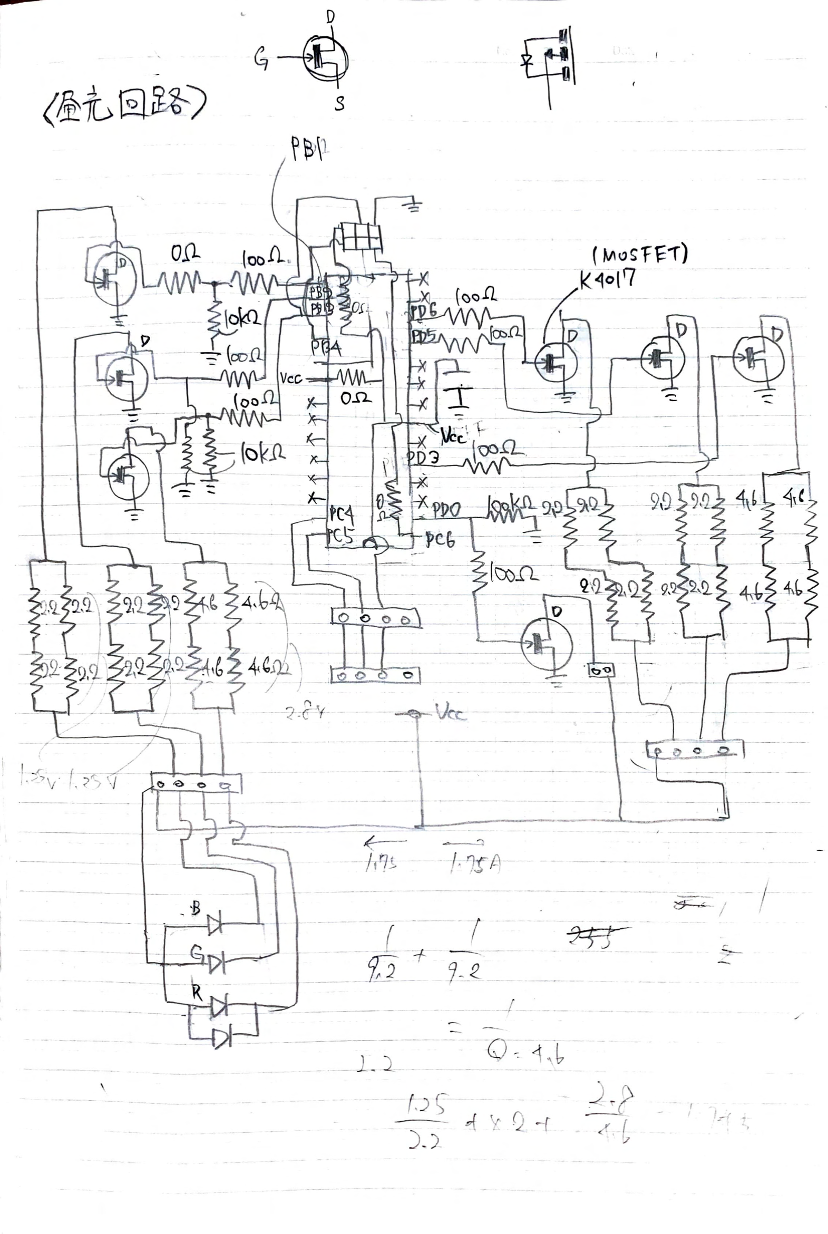
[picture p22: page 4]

直

(Mc,Sfr-r)
k <1°1 f7

．． ．

゜

—• | — —-_ ／
f | ／
・-―_,r-. | . 一 | ／
| ,r

＿ 1 ・・ク¥/ (. ? , ¥/

- 一ー

? "

ぐ

Y

＼

# -—~-ー_- ー ・ ・

-- ーマ

~
17i /. りti

幻

ー＋

1 N

―-

_ _ l
tJ~ ―

) )_

！ ヽ、

0 | 4

.{ 'yりィ

三

―--0 ＼ j

全

-c
I ー／ ~
」 | ・ 一 | ./

I .r(. : ,

## t, り一記路

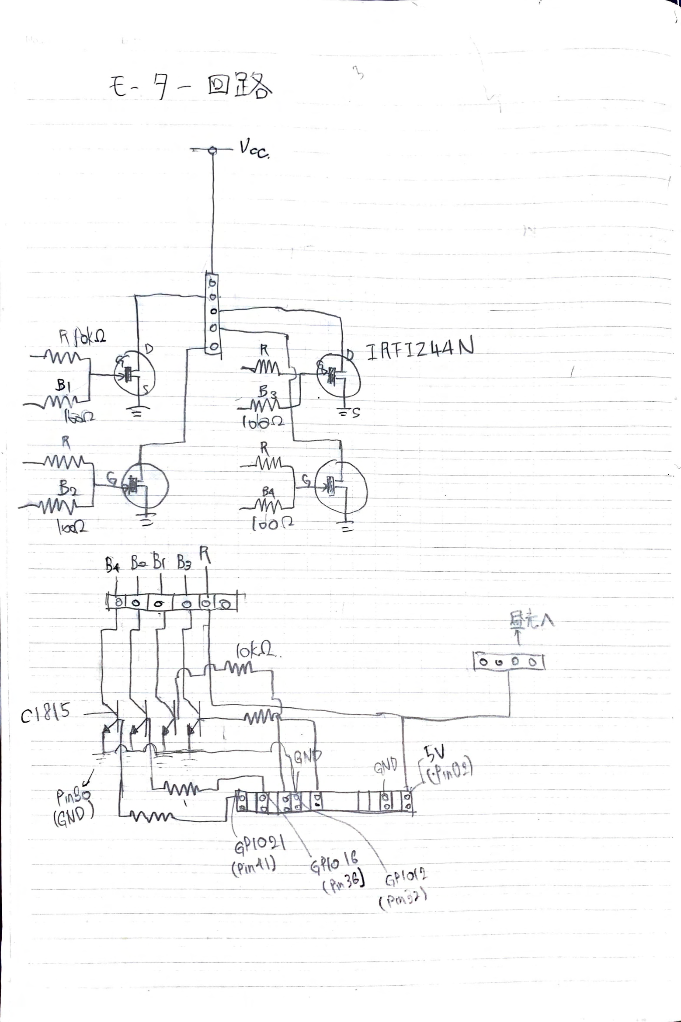
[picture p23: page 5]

‘‘ | ~~

や

＼ノ

I

__,

町立叫
」
. -.:1¥A | - -—:. -- -~- iv」叫〕-=----~ 一

［改of
_ _ __ JJ.t_ R-. Rr R., f¥

]¥_

+A~ .

・ 0

°

、UN

爪

n

娯
eqnv)
ー一ー一 応入＼ー）一→ 一'¥'.砂 砂仇
””‘

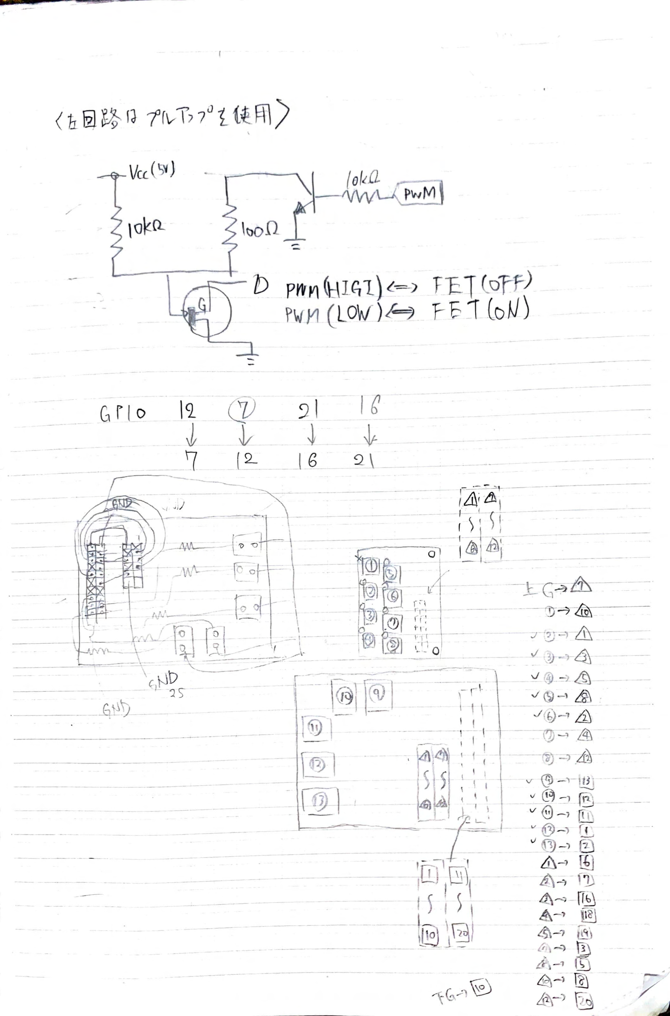
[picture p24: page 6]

〈這 絡 日プ（レ了', 勺｛詞

ノ鴫

如 5" .

\Q~Q.

# \~onf- [L -=

## D PW心 C,l)←) FE (off) p 1,/ YI L 'vJ)巳 f-5 LD"1)

②←

[

qr:

G r

。

―-

¢←

¥ ーー

ー 6

ー ＿ー

-＇． ー ー

# 広」――叶ーい国rtII

l9

ll

# I 一一心，；

＼

――

^}

（旧

# .II-I

ー

e-

―-

`
ーロ

祠

―＿一ー

lr

# ⑲二竺⑪ー＼II

ー,'［ー

＇

、

―――

ーり一-

―― ＇

，
凰）

ー

，

ヅi-
―

｝｀）竺'」、i.

••’

r.¥
― `-L¥

¥）

ヽ．＼

### り一―廿』

一

：
ふ

．

# _-― 一贔叩〗i[l_＿- ―_-― -＿――

遁＆• --` ＇
い］1-い△ —

咋 _.:.

J 2,;・ △

,1 炉') ~
v •,~ -) & v'()) -'、必＼．

✓ 1~-l ,QJ
(JJ-, 庖＼
~)• n V G) 史

氾うー 邑 V @-; 肛

"' → ~ ,.; f9→ 巳
&-J固
b'¥―ぅ 「']j
へ， 屈 → 囲

今ー？砂
芯今-)？隠陀

企→ 四

, —
／ A

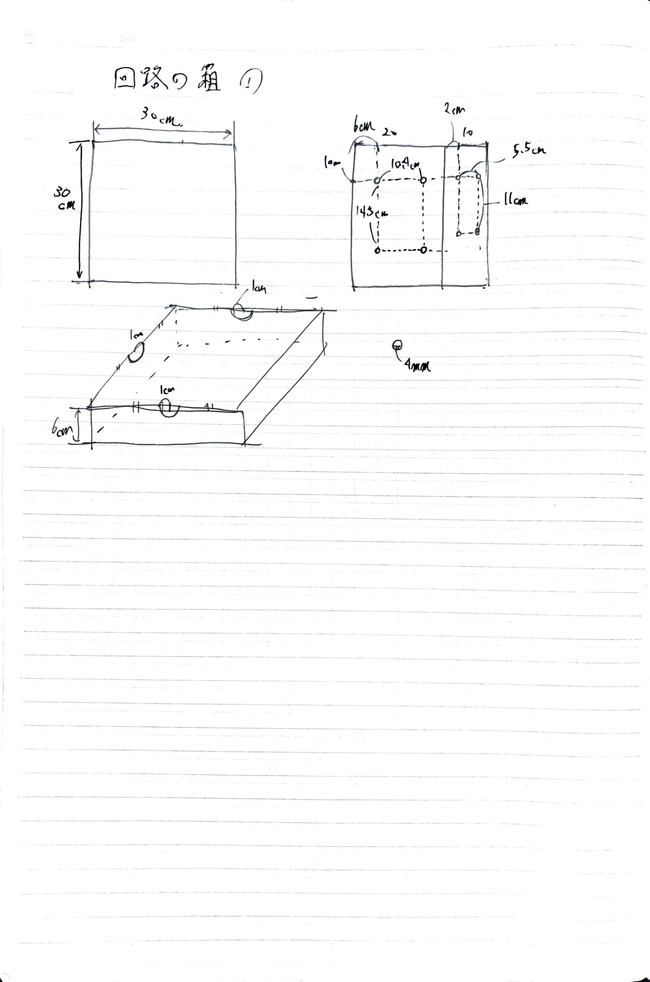
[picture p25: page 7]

## 臼応の廂 の

3 () 凡、

{(,,,_

## l l r 応 1 , ふ I •

裟 ,~~l'.I&-
¥! I
か— -----o - .

＼
'°"

~ 償爪

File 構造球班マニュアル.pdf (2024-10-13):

## 構造球班マニュアル（2020 年 ver）

作成：19 天田航

１．構造球パーツ

・投影筒
星を映すもの（一等星以外）。構成は塩ビ管の中にレンズと LED。LED なのに発熱するため、ヒート シンクがついている。


・星座絵
星座絵を投影するもの。缶に何座かは描いてあるが、一応中身を見て確認したほうがいい。また、星座 絵はすべてをつけるのではなく番組で使用するものだけを構造球につけるので、あらかじめ何の星座絵が 必要なのか番組班の人に聞いておく。


・一等星
星は投影筒で投影するといったが、一等星はこれで別に投影する。 ＜＜fig あとで

・アクリル板
五角形や六角形の形をした構造球の外殻。全部くみ上げるとサッカーボールと同じ形になる。また、アク リル板には MDF という物質で先端がとがったものがつけられている。これは組み立てのときにとても大切な ので壊さないように。また、アクリル板には 3 種類の穴が開いており、それぞれ用途が以下のようになってい る。


・モーター
構造球を動かし、星を回転させるために使用する。今使っているモーターはオリエンタルモーター株式会 社の『PK296A1-SG36』(2020 年 11 月)。モーターと土台を繋げているネジは予備がないのでなくさな いように。


・棒
構造球の軸。結構限界を迎えつつあり土台にうまく入らず、棒を削って入れることもある。 ＜＜fig＞＞

・土台
モーターと棒を置くところ。棒や回路, アクリルパネルを設置するとバランスを保てなくなるので、望遠鏡に 使用するウェイトを中におく。これも限界を迎えつつあるので新調したほうがいいかも。


・回路
投影筒らに電源を供給, 制御するためのもの。詳しい解説は回路班マニュアルの方で。 左が投影筒用, 右が一等星用。この 2 つは同一土台状にある。

星座絵用


２．組み立て手順

2-1. 部室での作業
(1) 土台に棒を刺す。上手く刺さらない場合は棒を削る
(2) モーターを取り付け、モーターと棒にバンドをぴんと張るように取り付ける。このときモーターは下のねじ をいじることで、位置を調節できる。


(3) アクリル板を六角ネジと金具を使って取り付けていく。このとき、棒の先端を 0 番として下図のように取 り付けていく。単純かつ人手がいる作業なので暇な人をかき集めて作業するとよい（ドーム係とか）。


MDF の先端の向く方向。所々おかしいので要検証

実際に上の構造球面番号, MDF の向いている方向にアクリル板を設置すると下図のようになる。0 番 から同心円状にアクリル板は設置していくと楽。また、アクリル板は内部の調節のために一部解体したりす るので、ねじ止めは緩く行う。


(4) アクリル板の上部を外して、棒に回路を設置する。回路はなるべく棒の先端近くに設置する。固定は スズランテープでする。
アクリル板の番号 | MDFの長い部分が向いている方向
0 | MDFの丸いネジ穴が03
1 | 15(おそらく3) | 16 | 12
2 | 1 | 17 | 27
3 | 13 | 18 | 14
4 | 14 | 19 | 29
5 | 15 | 20 | 30
6 | 16,11 | 21 | 20,30
7 | 12,17 | 22 | 16,26
8 | 14 | 23 | 27,28
9 | 14,19 | 24 | 14,18
10 | 15,20 | 25 | 29,30
11 | 20 | 26 | 16
12 | 2 | 27 | 17
13 | 17 | 28 | 27
14 | 19 | 29 | 28
15 | 19 | 30 | 26


設置が終わったら、回路班と交代。回路班に回路の配線をやってもらう（回路班マニュアル参照）。 それが終わると構造球から電源へのケーブルが数本出てくると思うので、それらをスズランテープでまとめてお く。ここで一度投影筒が光るか, 構造球が回るかを回路班とプログラミング班にチェックさせるのもあり。

(5) 回路にコードを刺していく。コードは投影筒が入っている段ボールにまとめて入っている（はず）。回 路に刺してそのままにしておくと先端がどこにいったか分からなくなるので、アクリル板の穴からコードの先端は 出しておいて、スズランテープで固定する。このとき、白い抵抗がたくさんある回路からのコードはアクリル板 の穴①から、他の回路からのコードは穴②に通す。
＜＜fig＞＞
(6) アクリル板の番号と対応する投影筒を取り出す。アクリル板の真ん中の穴から出しているコードと投 影筒を接続して、投影筒をアクリル板に刺す。そして、アクリル板の MDF の先端をクリップで固定する。こ

のとき 0 番に近いほうの投影筒が回路のヒートシンクと接触してしまうことがある。その時は長めの投影筒 の塩ビを切断する。


(7) 構造球を部室から体育館又は講堂に移動する。壊れやすいので注意。

2-2. 体育館または講堂での作業
(8) ドーム係にドームを膨らましてもらい、ドーム内に構造球を入れる。ドーム内は暗いので注意する。
(9) 星座絵をアクリル板に取り付ける。星座絵はアクリル板の穴③にネジとナットで固定する。このときナッ トを固定するために裏側へ手を伸ばさなければならない。方法としてはまだつけていない上面から手を伸ば すのもありだし、一度投影筒を外してそこから手を入れるもよし。また、星座絵にもアクリル板の番号との対 応があるので、その対応するアクリル板に設置する（オリオン座はアクリル板 12 番と対応しているなど）。

一応星座と投影筒の対応表はあるが、要確認

星座名 | 投影筒の番号
はくちょう | 5 | おとめ | 4
こと | 7 | しし | 8
わし | 9 | うしかい | 6
おうし | 2 | ペガスス | 1
ふたご | 13 | オリオン | 10

(10) 一等星をアクリル板に取り付ける。つけ方は星座絵と同じ。一等星には区別はないので、必要なと ころに設置する。しかし、一等星は星座絵のように直立しないので、必要なところから 2 つほど離れたアクリ ル板に設置する。


(10) すべての投影筒, 星座絵, 一等星が光るかプログラミング班に確認してもらう。
(11) 上面も設置し、投影筒, 星座絵, 一等星を取り付ける。
(12) 投影筒の位置を調節する。投影筒を光らせドームに投影された星がはっきりと見えるように（ボケ ないように）クリップを外して位置を調節する。これがすごく時間がかかる（らしい）。

３．解体手順
基本的に組み立ての逆を行う。異なる点は一番初めに構造球につながっている電源コードをすべて電 源から外しておく。

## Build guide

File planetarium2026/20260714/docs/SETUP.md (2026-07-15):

# 配線・導入

## 統括・モーター基板（XIAO ESP32C3）

`motor_driver_回路図.pdf` に合わせています。

| XIAO端子 | 信号 | 用途 |
|---|---|---|
| D0 | MO | SLA7078モニター入力 |
| D1 | M2 | 励磁モード設定 |
| D2 | CLOCK | ステップパルス |
| D3 | CW/CCW | 回転方向 |
| D4 | FLAG | ドライバー異常入力 |
| D5 | SYNC | 同期設定 |
| D6 | RESET | ドライバーリセット |
| D7 | M3 | 励磁モード設定 |
| D8 | M1 | 励磁モード設定 |
| D9 | ref/sleep_mcu | Sleep1制御（LOWでスリープ、通常動作はHIGH） |
| D10 | led_status | 状態LED |

`firmware/coordinator/platformio.ini` の設定値:

- `MOTOR_FULL_STEPS_PER_REV`: モーター単体のフルステップ/回転
- `MOTOR_MICROSTEPS`: SLA7078で設定した分割数
- `MOTOR_DIRECTION_INVERT`: 回転が逆なら1
- `MOTOR_MAX_OUTPUT_SPEED_DEG_SEC`: 出力軸の最高速度（度/秒）

使用モーターは **PK296A1-SG36（1.5 A/相、2.2 Ω/相）** を前提としています。モーター基本ステップ角1.8°、減速比36なので、出力軸基本ステップ角は0.05°、出力軸1回転は7,200パルスです。最高速度50 r/minを300°/sとして設定しています。

相電流1.5 Aの設定はソフトウェアではなく、SLA7078基板のVREF/電流設定回路で実機調整してください。

### 角度コマンド

- 通常値: 0°以上360°未満で管理します。360°は0°、720°も0°として扱います。
- 現在位置から同じ角度になる最も近い方向へ移動するため、連続回転後に何周も巻き戻しません。
- `999`: 指定速度で時計回りに連続回転します。
- `-999`: 指定速度で反時計回りに連続回転します。±999は物理角度ではなく専用コマンドです。
- 連続回転の停止: 速度を0°/sにするか、±999以外の目標角度を送ります。

### 再起動時の安全動作

- 再起動すると原点は未設定になります。
- 原点未設定中は通常角度指令と±999連続回転指令を拒否します。
- 校正画面のジョグ、相対移動、停止は原点合わせのため使用できます。
- 校正画面を開いた時点で直ちにSTOPを送り、速度入力の初期値は0°/sになります。
- 「現在位置を0°に設定」または「角度設定」を実行すると通常制御を解禁します。
- ライトは起動時に全OFFとなり、PC再接続後はモーターがロック中でもライト設定だけ復元します。
- UIと通信上の角度は0°以上360°未満で管理します。内部ステップ数だけは正確なパルス管理のため累積保持します。

## ライト基板

`seiza_ittose_回路図.pdf` に合わせています。

| 機能 | XIAO端子 |
|---|---|
| 恒星 | D0 |
| 一等星 | D1 |
| 星座1 | D7 |
| 星座2 | D8 |
| 星座3 | D9 |
| 星座4 | D10 |
| 星座5 | D5 |
| 星座6 | D4 |
| 星座7 | D3 |
| 星座8 | D2 |

恒星出力D0だけは回路上アクティブLOWです。論理ONでGPIO LOW、論理OFFでGPIO HIGHを出力します。一等星と星座1～8はアクティブHIGHです。UIと指示送信TXTには物理レベルではなく、通常どおり論理的なON/OFFを記述します。

## 構成

PCは統括・モーター基板へUSB/UART接続します。統括・モーター基板からライト基板へESP-NOWで指令を送り、ライト基板が反映状態を返信します。

統括・モーター基板のPC通信はXIAO ESP32C3のUSB CDCを使用します。USB通信はUSB-C端子内部のD+/D-を使用するため、外周端子D6（UART TX兼用）とD7（UART RX兼用）は通常GPIOとしてモーター回路に使用できます。

ESP32C3はシングルコアです。通信処理はFreeRTOSタスクで実行し、モーターのCLOCKパルス生成はハードウェアタイマー割り込みへ分離しています。したがって、ESP-NOWやJSON処理が動作している間もタイマー割り込みがステップ生成を継続します。

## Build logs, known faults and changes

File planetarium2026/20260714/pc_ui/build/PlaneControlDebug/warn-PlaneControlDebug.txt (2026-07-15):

This file lists modules PyInstaller was not able to find. This does not
necessarily mean this module is required for running your program. Python and
Python 3rd-party packages include a lot of conditional or optional modules. For
example the module 'ntpath' only exists on Windows, whereas the module
'posixpath' only exists on Posix systems.

Types if import:
* top-level: imported at the top-level - look at these first
* conditional: imported within an if-statement
* delayed: imported within a function
* optional: imported within a try-except-statement

IMPORTANT: Do NOT post this list to the issue-tracker. Use it as a basis for
            tracking down the missing module yourself. Thanks!

missing module named pep517 - imported by importlib.metadata (delayed)
missing module named 'org.python' - imported by copy (optional), xml.sax (delayed, conditional)
missing module named grp - imported by shutil (optional), tarfile (optional), pathlib (delayed, optional), subprocess (optional), distutils.archive_util (optional), setuptools._distutils.archive_util (optional)
missing module named pwd - imported by posixpath (delayed, conditional), shutil (optional), tarfile (optional), pathlib (delayed, conditional, optional), subprocess (optional), http.server (delayed, optional), webbrowser (delayed), netrc (delayed, conditional), getpass (delayed), distutils.util (delayed, conditional, optional), distutils.archive_util (optional), setuptools._distutils.util (delayed, conditional, optional), setuptools._distutils.archive_util (optional)
missing module named org - imported by pickle (optional)
missing module named posix - imported by os (conditional, optional), shutil (conditional), importlib._bootstrap_external (conditional)
missing module named resource - imported by posix (top-level), test.support (delayed, conditional, optional), test.libregrtest.setup (delayed, optional)
missing module named _frozen_importlib_external - imported by importlib._bootstrap (delayed), importlib (optional), importlib.abc (optional), zipimport (top-level)
excluded module named _frozen_importlib - imported by importlib (optional), importlib.abc (optional), zipimport (top-level)
missing module named _posixsubprocess - imported by subprocess (optional), multiprocessing.util (delayed)
missing module named typing_extensions - imported by packaging.version (conditional), packaging.specifiers (conditional), setuptools._reqs (conditional), setuptools.warnings (conditional), setuptools._path (conditional), setuptools.config.expand (conditional), setuptools.config.setupcfg (conditional), setuptools.config._apply_pyprojecttoml (conditional), setuptools.config.pyprojecttoml (conditional), setuptools.config._validate_pyproject.formats (conditional), setuptools._vendor.packaging.version (conditional), setuptools.config._validate_pyproject.error_reporting (conditional), setuptools.dist (conditional), setuptools.command.bdist_egg (conditional), setuptools.compat.py311 (conditional), setuptools.msvc (conditional), setuptools._distutils.util (conditional), setuptools._distutils.compilers.C.base (conditional), setuptools._distutils.cmd (conditional), setuptools._distutils.dist (conditional), setuptools._distutils.command.bdist (conditional), setuptools._distutils.sysconfig (conditional)
missing module named _posixshmem - imported by multiprocessing.resource_tracker (conditional), multiprocessing.shared_memory (conditional)
missing module named multiprocessing.set_start_method - imported by multiprocessing (top-level), multiprocessing.spawn (top-level)
missing module named multiprocessing.get_start_method - imported by multiprocessing (top-level), multiprocessing.spawn (top-level)
missing module named multiprocessing.get_context - imported by multiprocessing (top-level), multiprocessing.pool (top-level), multiprocessing.managers (top-level), multiprocessing.sharedctypes (top-level)
missing module named multiprocessing.TimeoutError - imported by multiprocessing (top-level), multiprocessing.pool (top-level)
missing module named _scproxy - imported by urllib.request (conditional)
missing module named termios - imported by serial.serialposix (top-level), tty (top-level), getpass (optional)
missing module named 'java.lang' - imported by platform (delayed, optional), xml.sax._exceptions (conditional)
missing module named multiprocessing.BufferTooShort - imported by multiprocessing (top-level), multiprocessing.connection (top-level)
missing module named multiprocessing.AuthenticationError - imported by multiprocessing (top-level), multiprocessing.connection (top-level)
missing module named asyncio.DefaultEventLoopPolicy - imported by asyncio (delayed, conditional), asyncio.events (delayed, conditional)
missing module named jaraco - imported by setuptools._reqs (top-level), setuptools._vendor.jaraco.functools (top-level), setuptools._vendor.jaraco.context (top-level), setuptools._vendor.jaraco.text (top-level)
missing module named vms_lib - imported by platform (delayed, optional)
missing module named java - imported by platform (delayed)
missing module named _winreg - imported by platform (delayed, optional)
missing module named 'distutils._modified' - imported by setuptools._distutils.file_util (delayed)
missing module named _typeshed - imported by setuptools.command.bdist_egg (conditional), setuptools.glob (conditional), setuptools._vendor.wheel.wheelfile (conditional), setuptools.compat.py311 (conditional), setuptools._distutils.dist (conditional)
excluded module named pkg_resources - imported by pygame.pkgdata (optional), packaging (top-level)
missing module named _manylinux - imported by packaging._manylinux (delayed, optional), setuptools._vendor.packaging._manylinux (delayed, optional)
missing module named 'distutils._log' - imported by setuptools._distutils.command.bdist_dumb (top-level), setuptools._distutils.command.bdist_rpm (top-level), setuptools._distutils.command.build_clib (top-level), setuptools._distutils.command.build_ext (top-level), setuptools._distutils.command.build_py (top-level), setuptools._distutils.command.build_scripts (top-level), setuptools._distutils.command.clean (top-level), setuptools._distutils.command.config (top-level), setuptools._distutils.command.install (top-level), setuptools._distutils.command.install_scripts (top-level), setuptools._distutils.command.sdist (top-level)
missing module named usercustomize - imported by site (delayed, optional)
missing module named sitecustomize - imported by site (delayed, optional)
missing module named readline - imported by site (delayed, optional), rlcompleter (optional), cmd (delayed, conditional, optional), code (delayed, conditional, optional), pdb (delayed, optional)
missing module named tomllib - imported by setuptools.compat.py310 (conditional)
missing module named 'typing.io' - imported by importlib.resources (top-level)
missing module named backports - imported by setuptools._vendor.jaraco.context (conditional)
missing module named importlib_resources - imported by setuptools._vendor.jaraco.text (optional)
missing module named trove_classifiers - imported by setuptools.config._validate_pyproject.formats (optional)
missing module named pyimod02_importers - imported by C:\Users\kazu2\Documents\Codex\2026-07-11\new-chat\work\pydeps39\PyInstaller\hooks\rthooks\pyi_rth_pkgutil.py (delayed)
missing module named StringIO - imported by pygame.tests.test_utils.test_machinery (optional), pygame.tests.test_utils.png (optional)
missing module named 'test.test_utils' - imported by pygame.tests.test_utils.run_tests (delayed, conditional), pygame.tests.__main__ (conditional), pygame.tests (conditional)
missing module named numpy - imported by pygame.surfarray (top-level), pygame.sndarray (top-level), pygame (delayed), pygame._camera_opencv (top-level), pygame.examples.arraydemo (delayed), pygame.examples.blit_blends (optional), pygame.examples.glcube (optional), pygame.examples.sound_array_demos (top-level), pygame.examples.vgrade (optional), pygame.tests.test_utils.png (delayed, optional), pygame.tests.mixer_test (delayed, optional), pygame.tests.pixelcopy_test (delayed, optional), pygame.tests.sndarray_tags (optional), pygame.tests.sndarray_test (top-level), pygame.tests.surfarray_tags (optional), pygame.tests.surfarray_test (top-level)
missing module named fcntl - imported by serial.serialposix (top-level), pygame.tests.test_utils.async_sub (conditional)
missing module named win32api - imported by pygame.tests.test_utils.async_sub (conditional, optional)
missing module named win32pipe - imported by pygame.tests.test_utils.async_sub (conditional, optional)
missing module named win32file - imported by pygame.tests.test_utils.async_sub (conditional, optional)
missing module named pygame.BufferError - imported by pygame (optional), pygame.tests.bufferproxy_test (optional)
missing module named pygame.register_quit - imported by pygame (top-level), pygame.fastevent (top-level)
missing module named pygame.error - imported by pygame (top-level), pygame.fastevent (top-level), pygame.camera (top-level)
missing module named pygame._sdl2.messagebox - imported by pygame._sdl2 (top-level), pygame.examples.video (top-level)
missing module named pygame._sdl2.get_drivers - imported by pygame._sdl2 (top-level), pygame.examples.video (top-level)
missing module named pygame._sdl2.Renderer - imported by pygame._sdl2 (top-level), pygame.examples.sprite_texture (top-level), pygame.examples.video (top-level)
missing module named pygame._sdl2.Image - imported by pygame._sdl2 (top-level), pygame.examples.sprite_texture (top-level), pygame.examples.video (top-level)
missing module named pygame._sdl2.Texture - imported by pygame._sdl2 (top-level), pygame.examples.sprite_texture (top-level), pygame.examples.video (top-level)
missing module named pygame._sdl2.Window - imported by pygame._sdl2 (top-level), pygame.examples.sprite_texture (top-level), pygame.examples.video (top-level)
missing module named 'numpy.random' - imported by pygame.examples.vgrade (optional)
missing module named 'OpenGL.GLU' - imported by pygame.examples.glcube (optional)
missing module named 'OpenGL.GL' - imported by pygame.examples.glcube (optional)
missing module named pygame.K_9 - imported by pygame (top-level), pygame.examples.blend_fill (top-level)
missing module named pygame.K_8 - imported by pygame (top-level), pygame.examples.blend_fill (top-level)
missing module named pygame.K_7 - imported by pygame (top-level), pygame.examples.blend_fill (top-level)
missing module named pygame.K_6 - imported by pygame (top-level), pygame.examples.blend_fill (top-level)
missing module named pygame.K_5 - imported by pygame (top-level), pygame.examples.blend_fill (top-level)
missing module named pygame.K_4 - imported by pygame (top-level), pygame.examples.blend_fill (top-level)
missing module named pygame.K_3 - imported by pygame (top-level), pygame.examples.blend_fill (top-level)
missing module named pygame.K_2 - imported by pygame (top-level), pygame.examples.blend_fill (top-level)
missing module named pygame.K_1 - imported by pygame (top-level), pygame.examples.blend_fill (top-level)
missing module named pygame._sdl2.AUDIO_ALLOW_FORMAT_CHANGE - imported by pygame._sdl2 (top-level), pygame.examples.audiocapture (top-level)
missing module named pygame._sdl2.AUDIO_F32 - imported by pygame._sdl2 (top-level), pygame.examples.audiocapture (top-level)
missing module named pygame._sdl2.AudioDevice - imported by pygame._sdl2 (top-level), pygame.examples.audiocapture (top-level)
missing module named pygame._sdl2.get_audio_device_names - imported by pygame._sdl2 (top-level), pygame.examples.audiocapture (top-level)
missing module named cv2 - imported by pygame._camera_opencv (top-level), pygame.camera (delayed, conditional, optional)
missing module named VideoCapture - imported by pygame._camera_vidcapture (delayed, optional)
missing module named vidcap - imported by pygame._camera_vidcapture (delayed, optional)
missing module named 'macholib.mach_o' - imported by PyInstaller.utils.osx (delayed, conditional)
missing module named 'macholib.util' - imported by PyInstaller.utils.osx (top-level)
missing module named 'macholib.MachO' - imported by PyInstaller.utils.osx (top-level)
missing module named macholib - imported by PyInstaller.utils.osx (top-level)
missing module named win32ctypes.core._time - imported by win32ctypes.core (top-level), win32ctypes.pywin32.win32api (top-level)
missing module named win32ctypes.core._system_information - imported by win32ctypes.core (top-level), win32ctypes.pywin32.win32api (top-level)
missing module named win32ctypes.core._resource - imported by win32ctypes.core (top-level), win32ctypes.pywin32.win32api (top-level)
missing module named win32ctypes.core._dll - imported by win32ctypes.core (top-level), win32ctypes.pywin32.win32api (top-level)
missing module named win32ctypes.core._common - imported by win32ctypes.core (top-level), win32ctypes.pywin32.win32api (top-level), win32ctypes.pywin32.win32cred (top-level)
missing module named win32ctypes.core._authentication - imported by win32ctypes.core (top-level), win32ctypes.pywin32.win32cred (top-level)
missing module named cffi - imported by win32ctypes.core (optional)
missing module named pygame.__file__ - imported by pygame (top-level), pygame.__pyinstaller.hook-pygame (top-level)
missing module named OpenGL - imported by pygame (delayed)
missing module named 'pygame.overlay' - imported by pygame (optional)
missing module named 'pygame.cdrom' - imported by pygame (conditional, optional)
missing module named 'System.IO' - imported by serial.serialcli (top-level)
missing module named System - imported by serial.serialcli (top-level)

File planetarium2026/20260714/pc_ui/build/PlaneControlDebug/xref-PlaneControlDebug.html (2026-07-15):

# modulegraph cross reference for app.py, pyi_rth__tkinter.py, pyi_rth_inspect.py, pyi_rth_multiprocessing.py, pyi_rth_pkgutil.py, pyi_rth_setuptools.py

app.py Script

imports: _bootlocale • _collections_abc • _weakrefset • abc • codecs • collections • collections.abc • copyreg • csv • datetime • encodings • encodings.aliases • encodings.ascii • encodings.base64_codec • encodings.big5 • encodings.big5hkscs • encodings.bz2_codec • encodings.charmap • encodings.cp037 • encodings.cp1006 • encodings.cp1026 • encodings.cp1125 • encodings.cp1140 • encodings.cp1250 • encodings.cp1251 • encodings.cp1252 • encodings.cp1253 • encodings.cp1254 • encodings.cp1255 • encodings.cp1256 • encodings.cp1257 • encodings.cp1258 • encodings.cp273 • encodings.cp424 • encodings.cp437 • encodings.cp500 • encodings.cp720 • encodings.cp737 • encodings.cp775 • encodings.cp850 • encodings.cp852 • encodings.cp855 • encodings.cp856 • encodings.cp857 • encodings.cp858 • encodings.cp860 • encodings.cp861 • encodings.cp862 • encodings.cp863 • encodings.cp864 • encodings.cp865 • encodings.cp866 • encodings.cp869 • encodings.cp874 • encodings.cp875 • encodings.cp932 • encodings.cp949 • encodings.cp950 • encodings.euc_jis_2004 • encodings.euc_jisx0213 • encodings.euc_jp • encodings.euc_kr • encodings.gb18030 • encodings.gb2312 • encodings.gbk • encodings.hex_codec • encodings.hp_roman8 • encodings.hz • encodings.idna • encodings.iso2022_jp • encodings.iso2022_jp_1 • encodings.iso2022_jp_2 • encodings.iso2022_jp_2004 • encodings.iso2022_jp_3 • encodings.iso2022_jp_ext • encodings.iso2022_kr • encodings.iso8859_1 • encodings.iso8859_10 • encodings.iso8859_11 • encodings.iso8859_13 • encodings.iso8859_14 • encodings.iso8859_15 • encodings.iso8859_16 • encodings.iso8859_2 • encodings.iso8859_3 • encodings.iso8859_4 • encodings.iso8859_5 • encodings.iso8859_6 • encodings.iso8859_7 • encodings.iso8859_8 • encodings.iso8859_9 • encodings.johab • encodings.koi8_r • encodings.koi8_t • encodings.koi8_u • encodings.kz1048 • encodings.latin_1 • encodings.mac_arabic • encodings.mac_croatian • encodings.mac_cyrillic • encodings.mac_farsi • encodings.mac_greek • encodings.mac_iceland • encodings.mac_latin2 • encodings.mac_roman • encodings.mac_romanian • encodings.mac_turkish • encodings.mbcs • encodings.oem • encodings.palmos • encodings.ptcp154 • encodings.punycode • encodings.quopri_codec • encodings.raw_unicode_escape • encodings.rot_13 • encodings.shift_jis • encodings.shift_jis_2004 • encodings.shift_jisx0213 • encodings.tis_620 • encodings.undefined • encodings.unicode_escape • encodings.utf_16 • encodings.utf_16_be • encodings.utf_16_le • encodings.utf_32 • encodings.utf_32_be • encodings.utf_32_le • encodings.utf_7 • encodings.utf_8 • encodings.utf_8_sig • encodings.uu_codec • encodings.zlib_codec • enum • functools • genericpath • heapq • io • json • keyword • linecache • locale • ntpath • operator • os • pathlib • posixpath • pygame • pygame.__pyinstaller • pygame.__pyinstaller.hook-pygame • pygame._camera • pygame._camera_opencv • pygame._camera_vidcapture • pygame._freetype • pygame._sdl2 • pygame._sdl2.audio • pygame._sdl2.controller • pygame._sdl2.mixer • pygame._sdl2.sdl2 • pygame._sdl2.touch • pygame._sdl2.video • pygame._sprite • pygame.base • pygame.bufferproxy • pygame.camera • pygame.color • pygame.colordict • pygame.constants • pygame.cursors • pygame.display • pygame.draw • pygame.draw_py • pygame.event • pygame.examples • pygame.examples.aacircle • pygame.examples.aliens • pygame.examples.arraydemo • pygame.examples.audiocapture • pygame.examples.blend_fill • pygame.examples.blit_blends • pygame.examples.camera • pygame.examples.chimp • pygame.examples.cursors • pygame.examples.dropevent • pygame.examples.eventlist • pygame.examples.font_viewer • pygame.examples.fonty • pygame.examples.freetype_misc • pygame.examples.glcube • pygame.examples.go_over_there • pygame.examples.grid • pygame.examples.headless_no_windows_needed • pygame.examples.joystick • pygame.examples.liquid • pygame.examples.mask • pygame.examples.midi • pygame.examples.moveit • pygame.examples.music_drop_fade • pygame.examples.pixelarray • pygame.examples.playmus • pygame.examples.resizing_new • pygame.examples.scaletest • pygame.examples.scrap_clipboard • pygame.examples.scroll • pygame.examples.setmodescale • pygame.examples.sound • pygame.examples.sound_array_demos • pygame.examples.sprite_texture • pygame.examples.stars • pygame.examples.testsprite • pygame.examples.textinput • pygame.examples.vgrade • pygame.examples.video • pygame.fastevent • pygame.font • pygame.freetype • pygame.ftfont • pygame.gfxdraw • pygame.image • pygame.imageext • pygame.joystick • pygame.key • pygame.locals • pygame.macosx • pygame.mask • pygame.math • pygame.midi • pygame.mixer • pygame.mixer_music • pygame.mouse • pygame.newbuffer • pygame.pixelarray • pygame.pixelcopy • pygame.pkgdata • pygame.pypm • pygame.rect • pygame.rwobject • pygame.scrap • pygame.sndarray • pygame.sprite • pygame.surface • pygame.surfarray • pygame.surflock • pygame.sysfont • pygame.tests • pygame.tests.__main__ • pygame.tests.base_test • pygame.tests.blit_test • pygame.tests.bufferproxy_test • pygame.tests.camera_test • pygame.tests.color_test • pygame.tests.constants_test • pygame.tests.controller_test • pygame.tests.cursors_test • pygame.tests.display_test • pygame.tests.docs_test • pygame.tests.draw_test • pygame.tests.event_test • pygame.tests.font_test • pygame.tests.freetype_tags • pygame.tests.freetype_test • pygame.tests.ftfont_tags • pygame.tests.ftfont_test • pygame.tests.gfxdraw_test • pygame.tests.image__save_gl_surface_test • pygame.tests.image_tags • pygame.tests.image_test • pygame.tests.imageext_tags • pygame.tests.imageext_test • pygame.tests.joystick_test • pygame.tests.key_test • pygame.tests.locals_test • pygame.tests.mask_test • pygame.tests.math_test • pygame.tests.midi_test • pygame.tests.mixer_music_tags • pygame.tests.mixer_music_test • pygame.tests.mixer_tags • pygame.tests.mixer_test • pygame.tests.mouse_test • pygame.tests.pixelarray_test • pygame.tests.pixelcopy_test • pygame.tests.rect_test • pygame.tests.run_tests__tests • pygame.tests.run_tests__tests.all_ok • pygame.tests.run_tests__tests.all_ok.fake_2_test • pygame.tests.run_tests__tests.all_ok.fake_3_test • pygame.tests.run_tests__tests.all_ok.fake_4_test • pygame.tests.run_tests__tests.all_ok.fake_5_test • pygame.tests.run_tests__tests.all_ok.fake_6_test • pygame.tests.run_tests__tests.all_ok.no_assertions__ret_code_of_1__test • pygame.tests.run_tests__tests.all_ok.zero_tests_test • pygame.tests.run_tests__tests.everything • pygame.tests.run_tests__tests.everything.fake_2_test • pygame.tests.run_tests__tests.everything.incomplete_todo_test • pygame.tests.run_tests__tests.everything.magic_tag_test • pygame.tests.run_tests__tests.everything.sleep_test • pygame.tests.run_tests__tests.exclude • pygame.tests.run_tests__tests.exclude.fake_2_test • pygame.tests.run_tests__tests.exclude.invisible_tag_test • pygame.tests.run_tests__tests.exclude.magic_tag_test • pygame.tests.run_tests__tests.failures1 • pygame.tests.run_tests__tests.failures1.fake_2_test • pygame.tests.run_tests__tests.failures1.fake_3_test • pygame.tests.run_tests__tests.failures1.fake_4_test • pygame.tests.run_tests__tests.incomplete • pygame.tests.run_tests__tests.incomplete.fake_2_test • pygame.tests.run_tests__tests.incomplete.fake_3_test • pygame.tests.run_tests__tests.incomplete_todo • pygame.tests.run_tests__tests.incomplete_todo.fake_2_test • pygame.tests.run_tests__tests.incomplete_todo.fake_3_test • pygame.tests.run_tests__tests.infinite_loop • pygame.tests.run_tests__tests.infinite_loop.fake_1_test • pygame.tests.run_tests__tests.infinite_loop.fake_2_test • pygame.tests.run_tests__tests.print_stderr • pygame.tests.run_tests__tests.print_stderr.fake_2_test • pygame.tests.run_tests__tests.print_stderr.fake_3_test • pygame.tests.run_tests__tests.print_stderr.fake_4_test • pygame.tests.run_tests__tests.print_stdout • pygame.tests.run_tests__tests.print_stdout.fake_2_test • pygame.tests.run_tests__tests.print_stdout.fake_3_test • pygame.tests.run_tests__tests.print_stdout.fake_4_test • pygame.tests.run_tests__tests.run_tests__test • pygame.tests.run_tests__tests.timeout • pygame.tests.run_tests__tests.timeout.fake_2_test • pygame.tests.run_tests__tests.timeout.sleep_test • pygame.tests.rwobject_test • pygame.tests.scrap_tags • pygame.tests.scrap_test • pygame.tests.sndarray_tags • pygame.tests.sndarray_test • pygame.tests.sprite_test • pygame.tests.surface_test • pygame.tests.surfarray_tags • pygame.tests.surfarray_test • pygame.tests.surflock_test • pygame.tests.sysfont_test • pygame.tests.test_utils • pygame.tests.test_utils.arrinter • pygame.tests.test_utils.async_sub • pygame.tests.test_utils.buftools • pygame.tests.test_utils.endian • pygame.tests.test_utils.png • pygame.tests.test_utils.run_tests • pygame.tests.test_utils.test_machinery • pygame.tests.test_utils.test_runner • pygame.tests.threads_test • pygame.tests.time_test • pygame.tests.touch_test • pygame.tests.transform_test • pygame.tests.version_test • pygame.tests.video_test • pygame.threads • pygame.time • pygame.transform • pygame.version • pyi_rth__tkinter.py • pyi_rth_inspect.py • pyi_rth_multiprocessing.py • pyi_rth_pkgutil.py • pyi_rth_setuptools.py • queue • re • reprlib • serial • serial.tools • serial.tools.list_ports • sre_compile • sre_constants • sre_parse • stat • sys • threading • time • tkinter • tkinter.filedialog • tkinter.messagebox • tkinter.ttk • traceback • types • warnings • weakref

pyi_rth__tkinter.py Script

imports: os • sys

imported by: app.py

pyi_rth_inspect.py Script

imports: inspect • os • sys

imported by: app.py

pyi_rth_multiprocessing.py Script

imports: multiprocessing • multiprocessing.spawn • subprocess • sys

imported by: app.py

pyi_rth_pkgutil.py Script

imports: pkgutil • pyimod02_importers

imported by: app.py

pyi_rth_setuptools.py Script

imports: _distutils_hack • os • setuptools

imported by: app.py

'OpenGL.GL' MissingModule

imported by: pygame.examples.glcube

'OpenGL.GLU' MissingModule

imported by: pygame.examples.glcube

'System.IO' MissingModule

imported by: serial.serialcli

'distutils._log' MissingModule

imported by: setuptools._distutils.command.bdist_dumb • setuptools._distutils.command.bdist_rpm • setuptools._distutils.command.build_clib • setuptools._distutils.command.build_ext • setuptools._distutils.command.build_py • setuptools._distutils.command.build_scripts • setuptools._distutils.command.clean • setuptools._distutils.command.config • setuptools._distutils.command.install • setuptools._distutils.command.install_scripts • setuptools._distutils.command.sdist

'distutils._modified' MissingModule

imported by: setuptools._distutils.file_util

'java.lang' MissingModule

imported by: platform • xml.sax._exceptions

'macholib.MachO' MissingModule

imported by: PyInstaller.utils.osx

'macholib.mach_o' MissingModule

imported by: PyInstaller.utils.osx

'macholib.util' MissingModule

imported by: PyInstaller.utils.osx

'numpy.random' MissingModule

imported by: pygame.examples.vgrade

'org.python' MissingModule

imported by: copy • xml.sax

'pygame.cdrom' MissingModule

imported by: pygame

'pygame.overlay' MissingModule

imported by: pygame

'test.test_utils' MissingModule

imported by: pygame.tests • pygame.tests.__main__ • pygame.tests.test_utils.run_tests

'typing.io' MissingModule

imported by: importlib.resources

OpenGL MissingModule

imported by: pygame

PyInstaller Package

imports: PyInstaller • PyInstaller.compat • PyInstaller.isolated • PyInstaller.log • os

imported by: PyInstaller • PyInstaller._shared_with_waf • PyInstaller.building • PyInstaller.building.utils • PyInstaller.compat • PyInstaller.config • PyInstaller.depend • PyInstaller.exceptions • PyInstaller.isolated • PyInstaller.isolated._parent • PyInstaller.lib • PyInstaller.log • PyInstaller.utils • PyInstaller.utils.hooks • PyInstaller.utils.hooks.conda • PyInstaller.utils.misc • PyInstaller.utils.osx

PyInstaller._shared_with_waf SourceModule

imports: PyInstaller • platform • re

imported by: PyInstaller.compat

PyInstaller.building Package

imports: PyInstaller

imported by: PyInstaller.building.utils

PyInstaller.building.utils SourceModule

imports: PyInstaller • PyInstaller.building • PyInstaller.compat • PyInstaller.config • PyInstaller.exceptions • PyInstaller.log • PyInstaller.utils • PyInstaller.utils.misc • PyInstaller.utils.osx • PyInstaller.utils.win32 • PyInstaller.utils.win32.versioninfo • fnmatch • glob • hashlib • marshal • os • pathlib • platform • py_compile • shutil • struct • subprocess • sys • zipfile

imported by: PyInstaller.depend.imphookapi

PyInstaller.compat SourceModule

imports: PyInstaller • PyInstaller._shared_with_waf • PyInstaller.exceptions • __future__ • ctypes.util • errno • importlib.machinery • importlib.metadata • importlib.util • importlib_metadata • os • packaging.version • platform • shutil • site • subprocess • sys • sysconfig • types • win32ctypes.pywin32 • win32ctypes.pywin32.pywintypes • win32ctypes.pywin32.win32api

imported by: PyInstaller • PyInstaller.building.utils • PyInstaller.exceptions • PyInstaller.isolated._parent • PyInstaller.utils.hooks • PyInstaller.utils.hooks.conda • PyInstaller.utils.misc • PyInstaller.utils.osx • PyInstaller.utils.win32.versioninfo

PyInstaller.config SourceModule

imports: PyInstaller

imported by: PyInstaller.building.utils • PyInstaller.isolated._parent • PyInstaller.utils.hooks

PyInstaller.depend Package

imports: PyInstaller

imported by: PyInstaller.depend.imphookapi

PyInstaller.depend.imphookapi SourceModule

imports: PyInstaller.building.utils • PyInstaller.depend • PyInstaller.lib.modulegraph.modulegraph

imported by: PyInstaller.utils.hooks

PyInstaller.exceptions SourceModule

imports: PyInstaller • PyInstaller.compat

imported by: PyInstaller.building.utils • PyInstaller.compat

PyInstaller.isolated Package

imports: PyInstaller • PyInstaller.isolated._parent

imported by: PyInstaller • PyInstaller.isolated._parent • PyInstaller.utils.hooks

PyInstaller.isolated._parent SourceModule

imports: PyInstaller • PyInstaller.compat • PyInstaller.config • PyInstaller.isolated • PyInstaller.log • base64 • ctypes • ctypes.wintypes • functools • marshal • msvcrt • os • pathlib • subprocess • sys

imported by: PyInstaller.isolated

PyInstaller.lib Package

imports: PyInstaller

imported by: PyInstaller.lib.modulegraph

PyInstaller.lib.modulegraph Package

imports: PyInstaller.lib • PyInstaller.lib.modulegraph • PyInstaller.lib.modulegraph.util

imported by: PyInstaller.lib.modulegraph • PyInstaller.lib.modulegraph.modulegraph • PyInstaller.lib.modulegraph.util

PyInstaller.lib.modulegraph.modulegraph SourceModule

imports: PyInstaller.lib.modulegraph • PyInstaller.lib.modulegraph.util • altgraph • altgraph.ObjectGraph • ast • collections • importlib._bootstrap_external • importlib.machinery • importlib.metadata • importlib.util • importlib_metadata • os • pkgutil • re • sys • urllib.request • warnings

imported by: PyInstaller.depend.imphookapi

PyInstaller.lib.modulegraph.util SourceModule

imports: PyInstaller.lib.modulegraph • dis • inspect

imported by: PyInstaller.lib.modulegraph • PyInstaller.lib.modulegraph.modulegraph

PyInstaller.log SourceModule

imports: PyInstaller • logging • os

imported by: PyInstaller • PyInstaller.building.utils • PyInstaller.isolated._parent • PyInstaller.utils.hooks • PyInstaller.utils.hooks.conda • PyInstaller.utils.misc • PyInstaller.utils.osx

PyInstaller.utils Package

imports: PyInstaller • PyInstaller.utils.misc

imported by: PyInstaller.building.utils • PyInstaller.utils.hooks • PyInstaller.utils.misc • PyInstaller.utils.osx • PyInstaller.utils.win32

PyInstaller.utils.hooks Package

imports: PyInstaller • PyInstaller.compat • PyInstaller.config • PyInstaller.depend.imphookapi • PyInstaller.isolated • PyInstaller.log • PyInstaller.utils • PyInstaller.utils.hooks • PyInstaller.utils.hooks.conda • __future__ • collections • copy • fnmatch • importlib • importlib.util • os • packaging.requirements • pathlib • pkgutil • subprocess • sys • textwrap • traceback • typing

imported by: PyInstaller.utils.hooks • PyInstaller.utils.hooks.conda • pygame.__pyinstaller.hook-pygame

PyInstaller.utils.hooks.conda SourceModule

imports: PyInstaller • PyInstaller.compat • PyInstaller.log • PyInstaller.utils.hooks • __future__ • collections • fnmatch • importlib.metadata • json • pathlib • sys • typing

imported by: PyInstaller.utils.hooks

PyInstaller.utils.misc SourceModule

imports: PyInstaller • PyInstaller.compat • PyInstaller.log • PyInstaller.utils • PyInstaller.utils.win32 • PyInstaller.utils.win32.versioninfo • codecs • glob • io • os • pathlib • pprint • re • tokenize

imported by: PyInstaller.building.utils • PyInstaller.utils • PyInstaller.utils.win32.versioninfo

PyInstaller.utils.osx SourceModule

imports: 'macholib.MachO' • 'macholib.mach_o' • 'macholib.util' • PyInstaller • PyInstaller.compat • PyInstaller.log • PyInstaller.utils • macholib • math • os • pathlib • shutil • subprocess • tempfile

imported by: PyInstaller.building.utils

PyInstaller.utils.win32 Package

imports: PyInstaller.utils • PyInstaller.utils.win32.versioninfo

imported by: PyInstaller.building.utils • PyInstaller.utils.misc • PyInstaller.utils.win32.versioninfo

PyInstaller.utils.win32.versioninfo SourceModule

imports: PyInstaller.compat • PyInstaller.utils.misc • PyInstaller.utils.win32 • pefile • struct

imported by: PyInstaller.building.utils • PyInstaller.utils.misc • PyInstaller.utils.win32

StringIO MissingModule

imported by: pygame.tests.test_utils.png • pygame.tests.test_utils.test_machinery

System MissingModule

imported by: serial.serialcli

VideoCapture MissingModule

imported by: pygame._camera_vidcapture

__future__ SourceModule

imported by: PyInstaller.compat • PyInstaller.utils.hooks • PyInstaller.utils.hooks.conda • codeop • doctest • importlib_metadata • importlib_metadata._meta • importlib_metadata.compat.py39 • packaging._elffile • packaging._manylinux • packaging._musllinux • packaging._parser • packaging._tokenizer • packaging.licenses • packaging.licenses._spdx • packaging.markers • packaging.requirements • packaging.specifiers • packaging.tags • packaging.utils • packaging.version • serial • serial.serialcli • serial.serialjava • serial.serialposix • serial.serialutil • serial.serialwin32 • serial.tools.list_ports • serial.tools.list_ports_common • serial.tools.list_ports_linux • serial.tools.list_ports_osx • serial.tools.list_ports_posix • serial.tools.list_ports_windows • serial.win32 • setuptools • setuptools._core_metadata • setuptools._distutils._modified • setuptools._distutils.archive_util • setuptools._distutils.cmd • setuptools._distutils.command.bdist • setuptools._distutils.command.build • setuptools._distutils.command.build_clib • setuptools._distutils.command.build_ext • setuptools._distutils.command.config • setuptools._distutils.command.install • setuptools._distutils.command.install_data • setuptools._distutils.command.install_lib • setuptools._distutils.command.sdist • setuptools._distutils.compat • setuptools._distutils.compilers.C.base • setuptools._distutils.compilers.C.msvc • setuptools._distutils.compilers.C.unix • setuptools._distutils.core • setuptools._distutils.dist • setuptools._distutils.extension • setuptools._distutils.fancy_getopt • setuptools._distutils.filelist • setuptools._distutils.spawn • setuptools._distutils.sysconfig • setuptools._distutils.util • setuptools._path • setuptools._reqs • setuptools._vendor.jaraco.context • setuptools._vendor.jaraco.functools • setuptools._vendor.packaging._elffile • setuptools._vendor.packaging._manylinux • setuptools._vendor.packaging._musllinux • setuptools._vendor.packaging._parser • setuptools._vendor.packaging._tokenizer • setuptools._vendor.packaging.markers • setuptools._vendor.packaging.requirements • setuptools._vendor.packaging.specifiers • setuptools._vendor.packaging.tags • setuptools._vendor.packaging.utils • setuptools._vendor.packaging.version • setuptools._vendor.tomli._parser • setuptools._vendor.tomli._re • setuptools._vendor.wheel • setuptools._vendor.wheel.macosx_libfile • setuptools._vendor.wheel.wheelfile • setuptools.command._requirestxt • setuptools.command.bdist_egg • setuptools.command.bdist_wheel • setuptools.command.build • setuptools.command.egg_info • setuptools.command.sdist • setuptools.compat.py311 • setuptools.config._apply_pyprojecttoml • setuptools.config._validate_pyproject.error_reporting • setuptools.config._validate_pyproject.formats • setuptools.config.expand • setuptools.config.pyprojecttoml • setuptools.config.setupcfg • setuptools.depends • setuptools.discovery • setuptools.dist • setuptools.errors • setuptools.extension • setuptools.glob • setuptools.installer • setuptools.monkey • setuptools.msvc • setuptools.warnings • test.libregrtest.runtest • test.libregrtest.runtest_mp

_abc (builtin module)

imported by: abc • test.libregrtest.refleak

_aix_support SourceModule

imports: _bootsubprocess • subprocess • sys • sysconfig

imported by: distutils.util • sysconfig

_ast (builtin module)

imported by: ast

_asyncio C:\Program Files\Python39\DLLs\_asyncio.pyd

imported by: asyncio.events • asyncio.futures • asyncio.tasks

_bisect (builtin module)

imported by: bisect

_blake2 (builtin module)

imported by: hashlib

_bootlocale SourceModule

imports: _locale • locale • sys

imported by: app.py • locale

_bootsubprocess SourceModule

imports: os

imported by: _aix_support

_bz2 C:\Program Files\Python39\DLLs\_bz2.pyd

imported by: bz2

_codecs (builtin module)

imported by: codecs

_codecs_cn (builtin module)

imported by: encodings.gb18030 • encodings.gb2312 • encodings.gbk • encodings.hz

_codecs_hk (builtin module)

imported by: encodings.big5hkscs

_codecs_iso2022 (builtin module)

imported by: encodings.iso2022_jp • encodings.iso2022_jp_1 • encodings.iso2022_jp_2 • encodings.iso2022_jp_2004 • encodings.iso2022_jp_3 • encodings.iso2022_jp_ext • encodings.iso2022_kr

_codecs_jp (builtin module)

imported by: encodings.cp932 • encodings.euc_jis_2004 • encodings.euc_jisx0213 • encodings.euc_jp • encodings.shift_jis • encodings.shift_jis_2004 • encodings.shift_jisx0213

_codecs_kr (builtin module)

imported by: encodings.cp949 • encodings.euc_kr • encodings.johab

_codecs_tw (builtin module)

imported by: encodings.big5 • encodings.cp950

_collections (builtin module)

imported by: collections • threading

_collections_abc SourceModule

imports: abc • sys • warnings

imported by: app.py • collections • collections.abc • contextlib • locale • os • pathlib • random • types • weakref

_compat_pickle SourceModule

imported by: _pickle • pickle

_compression SourceModule

imports: io

imported by: bz2 • gzip • lzma

_contextvars (builtin module)

imported by: contextvars

_csv (builtin module)

imported by: csv

_ctypes C:\Program Files\Python39\DLLs\_ctypes.pyd

imported by: ctypes • ctypes.macholib.dyld

_datetime (builtin module)

imports: _strptime • time

imported by: datetime

_decimal C:\Program Files\Python39\DLLs\_decimal.pyd

imported by: decimal

_distutils_hack Package

imports: importlib • importlib.abc • importlib.util • os • sys • traceback • warnings

imported by: _distutils_hack.override • pyi_rth_setuptools.py • setuptools

_distutils_hack.override SourceModule

imports: _distutils_hack

imported by: setuptools • setuptools.discovery

_elementtree C:\Program Files\Python39\DLLs\_elementtree.pyd

imports: pyexpat • xml.etree.ElementInclude • xml.etree.ElementPath • xml.etree.ElementTree • xml.etree.cElementTree

imported by: xml.etree.ElementTree

_frozen_importlib ExcludedModule

imported by: importlib • importlib.abc • zipimport

_frozen_importlib_external MissingModule

imported by: importlib • importlib._bootstrap • importlib.abc • zipimport

_functools (builtin module)

imported by: functools

_hashlib C:\Program Files\Python39\DLLs\_hashlib.pyd

imported by: hashlib • hmac

_heapq (builtin module)

imported by: heapq

_imp (builtin module)

imported by: distutils.sysconfig • importlib • importlib._bootstrap_external • importlib.machinery • importlib.util • setuptools._distutils.compat.py39 • sysconfig • zipimport

_io (builtin module)

imported by: importlib._bootstrap_external • io • unittest.mock • zipimport

_json (builtin module)

imports: json.decoder

imported by: json.decoder • json.encoder • json.scanner

_locale (builtin module)

imported by: _bootlocale • locale • re

_lzma C:\Program Files\Python39\DLLs\_lzma.pyd

imported by: lzma

_manylinux MissingModule

imported by: packaging._manylinux • setuptools._vendor.packaging._manylinux

_md5 (builtin module)

imported by: hashlib

_multibytecodec (builtin module)

imported by: encodings.big5 • encodings.big5hkscs • encodings.cp932 • encodings.cp949 • encodings.cp950 • encodings.euc_jis_2004 • encodings.euc_jisx0213 • encodings.euc_jp • encodings.euc_kr • encodings.gb18030 • encodings.gb2312 • encodings.gbk • encodings.hz • encodings.iso2022_jp • encodings.iso2022_jp_1 • encodings.iso2022_jp_2 • encodings.iso2022_jp_2004 • encodings.iso2022_jp_3 • encodings.iso2022_jp_ext • encodings.iso2022_kr • encodings.johab • encodings.shift_jis • encodings.shift_jis_2004 • encodings.shift_jisx0213

_multiprocessing C:\Program Files\Python39\DLLs\_multiprocessing.pyd

imported by: multiprocessing.connection • multiprocessing.queues • multiprocessing.resource_tracker • multiprocessing.synchronize • test.libregrtest.save_env

_opcode (builtin module)

imported by: opcode

_operator (builtin module)

imported by: hmac • operator

_osx_support SourceModule

imports: contextlib • distutils • distutils.log • os • re • sys • tempfile

imported by: distutils.sysconfig • distutils.util

_overlapped C:\Program Files\Python39\DLLs\_overlapped.pyd

imported by: asyncio.windows_events

_pickle (builtin module)

imports: _compat_pickle • codecs • copyreg

imported by: pickle

_posixshmem MissingModule

imported by: multiprocessing.resource_tracker • multiprocessing.shared_memory

_posixsubprocess MissingModule

imports: gc

imported by: multiprocessing.util • subprocess

_py_abc SourceModule

imports: _weakrefset

imported by: abc

_pydecimal SourceModule

imports: collections • contextvars • itertools • locale • math • numbers • re • sys

imported by: decimal

_queue C:\Program Files\Python39\DLLs\_queue.pyd

imported by: queue

_random (builtin module)

imported by: random

_scproxy MissingModule

imported by: urllib.request

_sha1 (builtin module)

imported by: hashlib

_sha256 (builtin module)

imported by: hashlib

_sha3 (builtin module)

imported by: hashlib

_sha512 (builtin module)

imported by: hashlib • random

_signal (builtin module)

imported by: signal

_sitebuiltins SourceModule

imports: os • pydoc • sys

imported by: site

_socket C:\Program Files\Python39\DLLs\_socket.pyd

imported by: socket

_sre (builtin module)

imports: copy • re

imported by: sre_compile • sre_constants

_ssl C:\Program Files\Python39\DLLs\_ssl.pyd

imports: socket

imported by: ssl

_stat (builtin module)

imported by: stat

_statistics (builtin module)

imported by: statistics

_string (builtin module)

imported by: string

_strptime SourceModule

imports: _thread • calendar • datetime • locale • re • time

imported by: _datetime • datetime • time

_struct (builtin module)

imported by: struct

_testcapi C:\Program Files\Python39\DLLs\_testcapi.pyd

imported by: test.support

_testinternalcapi C:\Program Files\Python39\DLLs\_testinternalcapi.pyd

imported by: test.support

_thread (builtin module)

imported by: _strptime • asyncio.base_futures • dataclasses • functools • reprlib • tempfile • test.support • threading

_threading_local SourceModule

imports: contextlib • threading • weakref

imported by: threading

_tkinter C:\Program Files\Python39\DLLs\_tkinter.pyd

imported by: tkinter

_tracemalloc (builtin module)

imported by: tracemalloc

_typeshed MissingModule

imported by: setuptools._distutils.dist • setuptools._vendor.wheel.wheelfile • setuptools.command.bdist_egg • setuptools.compat.py311 • setuptools.glob

_uuid C:\Program Files\Python39\DLLs\_uuid.pyd

imported by: uuid

_warnings (builtin module)

imported by: importlib._bootstrap_external • warnings

_weakref (builtin module)

imported by: _weakrefset • collections • weakref • xml.sax.expatreader

_weakrefset SourceModule

imports: _weakref • types

imported by: _py_abc • app.py • multiprocessing.process • threading • weakref

_winapi (builtin module)

imported by: asyncio.windows_events • asyncio.windows_utils • encodings • multiprocessing.connection • multiprocessing.heap • multiprocessing.popen_spawn_win32 • multiprocessing.reduction • multiprocessing.shared_memory • multiprocessing.spawn • subprocess • test.libregrtest.win_utils • test.support

_winreg MissingModule

imported by: platform

abc SourceModule

imports: _abc • _py_abc

imported by: _collections_abc • app.py • contextlib • email._policybase • functools • importlib.abc • importlib.metadata • importlib_metadata • inspect • io • multiprocessing.reduction • numbers • os • packaging.specifiers • pygame.camera • selectors • setuptools • setuptools._distutils.cmd • setuptools._vendor.packaging.specifiers • setuptools.config.setupcfg • typing

altgraph Package

imported by: PyInstaller.lib.modulegraph.modulegraph • altgraph.Graph • altgraph.GraphUtil • altgraph.ObjectGraph

altgraph.Graph SourceModule

imports: altgraph • collections

imported by: altgraph.GraphUtil • altgraph.ObjectGraph

altgraph.GraphUtil SourceModule

imports: altgraph • altgraph.Graph • collections • random

imported by: altgraph.ObjectGraph

altgraph.ObjectGraph SourceModule

imports: altgraph • altgraph.Graph • altgraph.GraphUtil

imported by: PyInstaller.lib.modulegraph.modulegraph

argparse SourceModule

imports: copy • gettext • os • re • shutil • sys • textwrap • warnings

imported by: ast • calendar • code • dis • doctest • gzip • http.server • inspect • serial.tools.list_ports • tarfile • test.libregrtest.cmdline • tokenize • trace • unittest.main • zipfile

array (builtin module)

imported by: multiprocessing.dummy • multiprocessing.managers • multiprocessing.reduction • pygame.tests.image_test • pygame.tests.mixer_test • pygame.tests.test_utils.png • serial.serialposix • serial.serialutil • socket

ast SourceModule

imports: _ast • argparse • collections • contextlib • enum • inspect • sys • warnings

imported by: PyInstaller.lib.modulegraph.modulegraph • inspect • packaging._parser • setuptools._vendor.packaging._parser • setuptools.config.expand

asyncio Package

imports: asyncio • asyncio.DefaultEventLoopPolicy • asyncio.base_events • asyncio.base_futures • asyncio.base_subprocess • asyncio.base_tasks • asyncio.constants • asyncio.coroutines • asyncio.events • asyncio.exceptions • asyncio.format_helpers • asyncio.futures • asyncio.locks • asyncio.proactor_events • asyncio.protocols • asyncio.queues • asyncio.runners • asyncio.selector_events • asyncio.sslproto • asyncio.staggered • asyncio.streams • asyncio.subprocess • asyncio.tasks • asyncio.threads • asyncio.transports • asyncio.trsock • asyncio.unix_events • asyncio.windows_events • asyncio.windows_utils • sys

imported by: asyncio • asyncio.base_events • asyncio.base_futures • asyncio.base_subprocess • asyncio.base_tasks • asyncio.constants • asyncio.coroutines • asyncio.events • asyncio.exceptions • asyncio.format_helpers • asyncio.futures • asyncio.locks • asyncio.log • asyncio.proactor_events • asyncio.protocols • asyncio.queues • asyncio.runners • asyncio.selector_events • asyncio.sslproto • asyncio.staggered • asyncio.streams • asyncio.subprocess • asyncio.tasks • asyncio.threads • asyncio.transports • asyncio.trsock • asyncio.unix_events • asyncio.windows_events • asyncio.windows_utils • test.libregrtest.save_env • unittest.async_case • unittest.mock

asyncio.DefaultEventLoopPolicy MissingModule

imported by: asyncio • asyncio.events

asyncio.base_events SourceModule

imports: asyncio • asyncio.constants • asyncio.coroutines • asyncio.events • asyncio.exceptions • asyncio.futures • asyncio.log • asyncio.protocols • asyncio.sslproto • asyncio.staggered • asyncio.tasks • asyncio.transports • asyncio.trsock • collections • collections.abc • concurrent.futures • functools • heapq • itertools • os • socket • ssl • stat • subprocess • sys • threading • time • traceback • warnings • weakref

imported by: asyncio • asyncio.proactor_events • asyncio.selector_events • asyncio.unix_events

asyncio.base_futures SourceModule

imports: _thread • asyncio • asyncio.format_helpers • reprlib

imported by: asyncio • asyncio.base_tasks • asyncio.coroutines • asyncio.futures

asyncio.base_subprocess SourceModule

imports: asyncio • asyncio.log • asyncio.protocols • asyncio.transports • collections • subprocess • warnings

imported by: asyncio • asyncio.unix_events • asyncio.windows_events

asyncio.base_tasks SourceModule

imports: asyncio • asyncio.base_futures • asyncio.coroutines • linecache • traceback

imported by: asyncio • asyncio.tasks

asyncio.constants SourceModule

imports: asyncio • enum

imported by: asyncio • asyncio.base_events • asyncio.coroutines • asyncio.format_helpers • asyncio.proactor_events • asyncio.selector_events • asyncio.sslproto • asyncio.unix_events

asyncio.coroutines SourceModule

imports: asyncio • asyncio.base_futures • asyncio.constants • asyncio.format_helpers • asyncio.log • collections.abc • functools • inspect • os • sys • traceback • types • warnings

imported by: asyncio • asyncio.base_events • asyncio.base_tasks • asyncio.runners • asyncio.streams • asyncio.tasks • asyncio.unix_events

asyncio.events SourceModule

imports: _asyncio • asyncio • asyncio.DefaultEventLoopPolicy • asyncio.format_helpers • contextvars • os • socket • subprocess • sys • threading

imported by: asyncio • asyncio.base_events • asyncio.futures • asyncio.locks • asyncio.queues • asyncio.runners • asyncio.selector_events • asyncio.staggered • asyncio.streams • asyncio.subprocess • asyncio.tasks • asyncio.threads • asyncio.unix_events • asyncio.windows_events • test.support

asyncio.exceptions SourceModule

imports: asyncio

imported by: asyncio • asyncio.base_events • asyncio.futures • asyncio.locks • asyncio.proactor_events • asyncio.staggered • asyncio.streams • asyncio.tasks • asyncio.unix_events • asyncio.windows_events

asyncio.format_helpers SourceModule

imports: asyncio • asyncio.constants • functools • inspect • reprlib • sys • traceback

imported by: asyncio • asyncio.base_futures • asyncio.coroutines • asyncio.events • asyncio.futures • asyncio.streams

asyncio.futures SourceModule

imports: _asyncio • asyncio • asyncio.base_futures • asyncio.events • asyncio.exceptions • asyncio.format_helpers • concurrent.futures • contextvars • logging • sys

imported by: asyncio • asyncio.base_events • asyncio.proactor_events • asyncio.selector_events • asyncio.tasks • asyncio.unix_events • asyncio.windows_events

asyncio.locks SourceModule

imports: asyncio • asyncio.events • asyncio.exceptions • collections • warnings

imported by: asyncio • asyncio.queues • asyncio.staggered

asyncio.log SourceModule

imports: asyncio • logging

imported by: asyncio.base_events • asyncio.base_subprocess • asyncio.coroutines • asyncio.proactor_events • asyncio.selector_events • asyncio.sslproto • asyncio.streams • asyncio.subprocess • asyncio.unix_events • asyncio.windows_events

asyncio.proactor_events SourceModule

imports: asyncio • asyncio.base_events • asyncio.constants • asyncio.exceptions • asyncio.futures • asyncio.log • asyncio.protocols • asyncio.sslproto • asyncio.transports • asyncio.trsock • collections • io • os • signal • socket • threading • warnings

imported by: asyncio • asyncio.windows_events

asyncio.protocols SourceModule

imports: asyncio

imported by: asyncio • asyncio.base_events • asyncio.base_subprocess • asyncio.proactor_events • asyncio.selector_events • asyncio.sslproto • asyncio.streams • asyncio.subprocess

asyncio.queues SourceModule

imports: asyncio • asyncio.events • asyncio.locks • collections • heapq • warnings

imported by: asyncio • asyncio.tasks

asyncio.runners SourceModule

imports: asyncio • asyncio.coroutines • asyncio.events • asyncio.tasks

imported by: asyncio

asyncio.selector_events SourceModule

imports: asyncio • asyncio.base_events • asyncio.constants • asyncio.events • asyncio.futures • asyncio.log • asyncio.protocols • asyncio.sslproto • asyncio.transports • asyncio.trsock • collections • errno • functools • selectors • socket • ssl • warnings • weakref

imported by: asyncio • asyncio.unix_events • asyncio.windows_events

asyncio.sslproto SourceModule

imports: asyncio • asyncio.constants • asyncio.log • asyncio.protocols • asyncio.transports • collections • ssl • warnings

imported by: asyncio • asyncio.base_events • asyncio.proactor_events • asyncio.selector_events

asyncio.staggered SourceModule

imports: asyncio • asyncio.events • asyncio.exceptions • asyncio.locks • asyncio.tasks • contextlib • typing

imported by: asyncio • asyncio.base_events

asyncio.streams SourceModule

imports: asyncio • asyncio.coroutines • asyncio.events • asyncio.exceptions • asyncio.format_helpers • asyncio.log • asyncio.protocols • asyncio.tasks • socket • sys • warnings • weakref

imported by: asyncio • asyncio.subprocess

asyncio.subprocess SourceModule

imports: asyncio • asyncio.events • asyncio.log • asyncio.protocols • asyncio.streams • asyncio.tasks • subprocess • warnings

imported by: asyncio

asyncio.tasks SourceModule

imports: _asyncio • asyncio • asyncio.base_tasks • asyncio.coroutines • asyncio.events • asyncio.exceptions • asyncio.futures • asyncio.queues • concurrent.futures • contextvars • functools • inspect • itertools • types • warnings • weakref

imported by: asyncio • asyncio.base_events • asyncio.runners • asyncio.staggered • asyncio.streams • asyncio.subprocess • asyncio.unix_events • asyncio.windows_events

asyncio.threads SourceModule

imports: asyncio • asyncio.events • contextvars • functools

imported by: asyncio

asyncio.transports SourceModule

imports: asyncio

imported by: asyncio • asyncio.base_events • asyncio.base_subprocess • asyncio.proactor_events • asyncio.selector_events • asyncio.sslproto • asyncio.unix_events

asyncio.trsock SourceModule

imports: asyncio • socket • warnings

imported by: asyncio • asyncio.base_events • asyncio.proactor_events • asyncio.selector_events

asyncio.unix_events SourceModule

imports: asyncio • asyncio.base_events • asyncio.base_subprocess • asyncio.constants • asyncio.coroutines • asyncio.events • asyncio.exceptions • asyncio.futures • asyncio.log • asyncio.selector_events • asyncio.tasks • asyncio.transports • errno • io • itertools • os • selectors • signal • socket • stat • subprocess • sys • threading • warnings

imported by: asyncio

asyncio.windows_events SourceModule

imports: _overlapped • _winapi • asyncio • asyncio.base_subprocess • asyncio.events • asyncio.exceptions • asyncio.futures • asyncio.log • asyncio.proactor_events • asyncio.selector_events • asyncio.tasks • asyncio.windows_utils • errno • math • msvcrt • socket • struct • sys • time • weakref

imported by: asyncio

asyncio.windows_utils SourceModule

imports: _winapi • asyncio • itertools • msvcrt • os • subprocess • sys • tempfile • warnings

imported by: asyncio • asyncio.windows_events

atexit (builtin module)

imported by: logging • multiprocessing.util • pygame • pygame.midi • rlcompleter • site • test.libregrtest.setup • weakref

backports MissingModule

imported by: setuptools._vendor.jaraco.context

base64 SourceModule

imports: binascii • getopt • re • struct • sys

imported by: PyInstaller.isolated._parent • email._encoded_words • email.base64mime • email.encoders • encodings.base64_codec • http.server • secrets • setuptools._vendor.wheel.wheelfile • ssl • urllib.request • xmlrpc.client

bdb SourceModule

imports: fnmatch • inspect • linecache • os • reprlib • sys

imported by: pdb

binascii (builtin module)

imported by: base64 • email._encoded_words • email.base64mime • email.contentmanager • email.header • encodings.hex_codec • encodings.uu_codec • http.server • pygame.tests.image_test • pygame.tests.test_utils.png • quopri • secrets • uu • zipfile

bisect SourceModule

imports: _bisect

imported by: multiprocessing.heap • random • setuptools._vendor.more_itertools.recipes • statistics • urllib.request

builtins (builtin module)

imported by: bz2 • codecs • dataclasses • doctest • gettext • gzip • inspect • locale • lzma • operator • pydoc • reprlib • rlcompleter • setuptools.config._validate_pyproject.formats • site • subprocess • tarfile • test.libregrtest.save_env • tokenize • unittest.mock • warnings

bz2 SourceModule

imports: _bz2 • _compression • builtins • io • os • threading

imported by: encodings.bz2_codec • shutil • tarfile • test.support • zipfile

calendar SourceModule

imports: argparse • datetime • itertools • locale • sys

imported by: _strptime • email._parseaddr • http.cookiejar • ssl

cffi MissingModule

imported by: win32ctypes.core

cgi SourceModule

imports: collections.abc • email.message • email.parser • html • io • locale • os • re • sys • tempfile • traceback • urllib.parse

imported by: distutils.config

cmd SourceModule

imports: readline • string • sys

imported by: pdb

code SourceModule

imports: argparse • codeop • readline • sys • traceback

imported by: pdb

codecs SourceModule

imports: _codecs • builtins • encodings • sys

imported by: PyInstaller.utils.misc • _pickle • app.py • encodings • encodings.ascii • encodings.base64_codec • encodings.big5 • encodings.big5hkscs • encodings.bz2_codec • encodings.charmap • encodings.cp037 • encodings.cp1006 • encodings.cp1026 • encodings.cp1125 • encodings.cp1140 • encodings.cp1250 • encodings.cp1251 • encodings.cp1252 • encodings.cp1253 • encodings.cp1254 • encodings.cp1255 • encodings.cp1256 • encodings.cp1257 • encodings.cp1258 • encodings.cp273 • encodings.cp424 • encodings.cp437 • encodings.cp500 • encodings.cp720 • encodings.cp737 • encodings.cp775 • encodings.cp850 • encodings.cp852 • encodings.cp855 • encodings.cp856 • encodings.cp857 • encodings.cp858 • encodings.cp860 • encodings.cp861 • encodings.cp862 • encodings.cp863 • encodings.cp864 • encodings.cp865 • encodings.cp866 • encodings.cp869 • encodings.cp874 • encodings.cp875 • encodings.cp932 • encodings.cp949 • encodings.cp950 • encodings.euc_jis_2004 • encodings.euc_jisx0213 • encodings.euc_jp • encodings.euc_kr • encodings.gb18030 • encodings.gb2312 • encodings.gbk • encodings.hex_codec • encodings.hp_roman8 • encodings.hz • encodings.idna • encodings.iso2022_jp • encodings.iso2022_jp_1 • encodings.iso2022_jp_2 • encodings.iso2022_jp_2004 • encodings.iso2022_jp_3 • encodings.iso2022_jp_ext • encodings.iso2022_kr • encodings.iso8859_1 • encodings.iso8859_10 • encodings.iso8859_11 • encodings.iso8859_13 • encodings.iso8859_14 • encodings.iso8859_15 • encodings.iso8859_16 • encodings.iso8859_2 • encodings.iso8859_3 • encodings.iso8859_4 • encodings.iso8859_5 • encodings.iso8859_6 • encodings.iso8859_7 • encodings.iso8859_8 • encodings.iso8859_9 • encodings.johab • encodings.koi8_r • encodings.koi8_t • encodings.koi8_u • encodings.kz1048 • encodings.latin_1 • encodings.mac_arabic • encodings.mac_croatian • encodings.mac_cyrillic • encodings.mac_farsi • encodings.mac_greek • encodings.mac_iceland • encodings.mac_latin2 • encodings.mac_roman • encodings.mac_romanian • encodings.mac_turkish • encodings.mbcs • encodings.oem • encodings.palmos • encodings.ptcp154 • encodings.punycode • encodings.quopri_codec • encodings.raw_unicode_escape • encodings.rot_13 • encodings.shift_jis • encodings.shift_jis_2004 • encodings.shift_jisx0213 • encodings.tis_620 • encodings.undefined • encodings.unicode_escape • encodings.utf_16 • encodings.utf_16_be • encodings.utf_16_le • encodings.utf_32 • encodings.utf_32_be • encodings.utf_32_le • encodings.utf_7 • encodings.utf_8 • encodings.utf_8_sig • encodings.uu_codec • encodings.zlib_codec • json • pefile • pickle • tokenize • xml.sax.saxutils

codeop SourceModule

imports: __future__ • warnings

imported by: code

collections Package

imports: _collections • _collections_abc • _weakref • copy • heapq • itertools • keyword • operator • reprlib • sys • warnings

imported by: PyInstaller.lib.modulegraph.modulegraph • PyInstaller.utils.hooks • PyInstaller.utils.hooks.conda • _pydecimal • altgraph.Graph • altgraph.GraphUtil • app.py • ast • asyncio.base_events • asyncio.base_subprocess • asyncio.locks • asyncio.proactor_events • asyncio.queues • asyncio.selector_events • asyncio.sslproto • collections.abc • concurrent.futures._base • configparser • contextlib • difflib • dis • doctest • email.feedparser • functools • importlib.metadata • importlib_metadata • importlib_metadata._collections • importlib_metadata._itertools • inspect • multiprocessing.heap • multiprocessing.pool • multiprocessing.queues • packaging._manylinux • pefile • pkgutil • platform • pprint • pydoc • pygame.draw_py • pygame.tests.event_test • pygame.tests.mask_test • queue • selectors • setuptools._distutils.command.install • setuptools._vendor.more_itertools.more • setuptools._vendor.more_itertools.recipes • setuptools._vendor.packaging._manylinux • setuptools.command._requirestxt • setuptools.config._validate_pyproject.extra_validations • setuptools.config.setupcfg • shlex • shutil • ssl • statistics • string • threading • tokenize • traceback • typing • unittest._log • unittest.case • unittest.util • urllib.parse • win32ctypes.pywin32.pywintypes • xml.etree.ElementTree • zipp._functools

collections.abc SourceModule

imports: _collections_abc • collections

imported by: app.py • asyncio.base_events • asyncio.coroutines • cgi • configparser • http.client • importlib_metadata • importlib_metadata._meta • inspect • logging • packaging.tags • pygame.tests.color_test • pygame.tests.math_test • pygame.tests.rect_test • selectors • setuptools • setuptools._distutils._modified • setuptools._distutils.cmd • setuptools._distutils.command.bdist • setuptools._distutils.command.build • setuptools._distutils.command.build_clib • setuptools._distutils.command.build_ext • setuptools._distutils.command.config • setuptools._distutils.command.install_data • setuptools._distutils.command.sdist • setuptools._distutils.compat • setuptools._distutils.compilers.C.base • setuptools._distutils.compilers.C.msvc • setuptools._distutils.compilers.C.unix • setuptools._distutils.core • setuptools._distutils.dist • setuptools._distutils.extension • setuptools._distutils.fancy_getopt • setuptools._distutils.filelist • setuptools._distutils.spawn • setuptools._distutils.util • setuptools._reqs • setuptools._vendor.jaraco.context • setuptools._vendor.jaraco.functools • setuptools._vendor.more_itertools.more • setuptools._vendor.tomli._parser • setuptools.command._requirestxt • setuptools.command.bdist_egg • setuptools.command.bdist_wheel • setuptools.command.egg_info • setuptools.command.sdist • setuptools.config._apply_pyprojecttoml • setuptools.config.expand • setuptools.config.pyprojecttoml • setuptools.config.setupcfg • setuptools.discovery • setuptools.dist • setuptools.extension • setuptools.glob • setuptools.wheel • test.libregrtest.refleak • test.support • tracemalloc • typing • xml.etree.ElementTree

concurrent Package

imported by: concurrent.futures

concurrent.futures Package

imports: concurrent • concurrent.futures._base • concurrent.futures.process • concurrent.futures.thread

imported by: asyncio.base_events • asyncio.futures • asyncio.tasks • concurrent.futures._base • concurrent.futures.process • concurrent.futures.thread • distutils.command.build_ext • setuptools._distutils.command.build_ext

concurrent.futures._base SourceModule

imports: collections • concurrent.futures • logging • threading • time • types

imported by: concurrent.futures • concurrent.futures.process • concurrent.futures.thread

concurrent.futures.process SourceModule

imports: concurrent.futures • concurrent.futures._base • functools • itertools • multiprocessing • multiprocessing.connection • multiprocessing.queues • os • queue • sys • threading • traceback • weakref

imported by: concurrent.futures

concurrent.futures.thread SourceModule

imports: concurrent.futures • concurrent.futures._base • itertools • os • queue • threading • types • weakref

imported by: concurrent.futures

configparser SourceModule

imports: collections • collections.abc • functools • io • itertools • os • re • sys • warnings

imported by: distutils.config • distutils.dist • importlib.metadata • setuptools._distutils.dist • setuptools.command.setopt • setuptools.config.expand • setuptools.dist • setuptools.unicode_utils

contextlib SourceModule

imports: _collections_abc • abc • collections • functools • sys • types

imported by: _osx_support • _threading_local • ast • asyncio.staggered • distutils.command.build_ext • getpass • glob • http.server • importlib._common • importlib.metadata • importlib.resources • importlib.util • importlib_metadata • packaging._manylinux • packaging._tokenizer • setuptools._distutils.command.build_ext • setuptools._distutils.command.check • setuptools._distutils.command.install • setuptools._distutils.compilers.C.msvc • setuptools._distutils.dist • setuptools._distutils.version • setuptools._path • setuptools._vendor.jaraco.context • setuptools._vendor.more_itertools.more • setuptools._vendor.more_itertools.recipes • setuptools._vendor.packaging._manylinux • setuptools._vendor.packaging._tokenizer • setuptools.archive_util • setuptools.command.sdist • setuptools.config._validate_pyproject.error_reporting • setuptools.config.pyprojecttoml • setuptools.config.setupcfg • setuptools.depends • setuptools.msvc • setuptools.wheel • subprocess • test.support • typing • unittest.case • unittest.mock • urllib.request • win32ctypes.pywin32.pywintypes • xml.etree.ElementTree • zipfile

contextvars SourceModule

imports: _contextvars

imported by: _pydecimal • asyncio.events • asyncio.futures • asyncio.tasks • asyncio.threads

copy SourceModule

imports: 'org.python' • copyreg • types • weakref

imported by: PyInstaller.utils.hooks • _sre • argparse • collections • dataclasses • email.generator • gettext • http.cookiejar • http.server • pefile • pygame.tests.mask_test • setuptools._distutils.compilers.C.cygwin • tarfile • weakref • webbrowser • xml.etree.ElementInclude

copyreg SourceModule

imported by: _pickle • app.py • copy • multiprocessing.reduction • pickle • pygame • re • test.libregrtest.refleak

csv SourceModule

imports: _csv • io • re

imported by: app.py • importlib.metadata • importlib_metadata • setuptools._vendor.wheel.wheelfile

ctypes Package

imports: _ctypes • ctypes._endian • nt • os • struct • sys • types

imported by: PyInstaller.isolated._parent • ctypes._aix • ctypes._endian • ctypes.macholib • ctypes.util • ctypes.wintypes • multiprocessing.sharedctypes • packaging._manylinux • pygame.examples.glcube • pygame.tests.base_test • pygame.tests.bufferproxy_test • pygame.tests.color_test • pygame.tests.freetype_test • pygame.tests.mixer_test • pygame.tests.pixelcopy_test • pygame.tests.surface_test • pygame.tests.test_utils.arrinter • pygame.tests.test_utils.async_sub • pygame.tests.test_utils.buftools • serial.serialwin32 • serial.tools.list_ports_osx • serial.tools.list_ports_windows • serial.win32 • setuptools._vendor.packaging._manylinux • setuptools._vendor.wheel.macosx_libfile • setuptools.windows_support • test.support • win32ctypes.core.ctypes._authentication • win32ctypes.core.ctypes._common • win32ctypes.core.ctypes._resource • win32ctypes.core.ctypes._system_information • win32ctypes.core.ctypes._util • win32ctypes.pywin32.win32cred

ctypes._aix SourceModule

imports: ctypes • os • re • subprocess • sys

imported by: ctypes.util

ctypes._endian SourceModule

imports: ctypes • sys

imported by: ctypes

ctypes.macholib Package

imports: ctypes

imported by: ctypes.macholib.dyld • ctypes.macholib.dylib • ctypes.macholib.framework

ctypes.macholib.dyld SourceModule

imports: _ctypes • ctypes.macholib • ctypes.macholib.dylib • ctypes.macholib.framework • itertools • os

imported by: ctypes.util

ctypes.macholib.dylib SourceModule

imports: ctypes.macholib • re

imported by: ctypes.macholib.dyld

ctypes.macholib.framework SourceModule

imports: ctypes.macholib • re

imported by: ctypes.macholib.dyld

ctypes.util SourceModule

imports: ctypes • ctypes._aix • ctypes.macholib.dyld • importlib.machinery • os • re • shutil • struct • subprocess • sys • tempfile

imported by: PyInstaller.compat • test.support

ctypes.wintypes SourceModule

imports: ctypes

imported by: PyInstaller.isolated._parent • pygame.tests.test_utils.async_sub • serial.tools.list_ports_windows • serial.win32 • setuptools.windows_support • test.support • win32ctypes.core.ctypes._authentication • win32ctypes.core.ctypes._common • win32ctypes.core.ctypes._dll • win32ctypes.core.ctypes._nl_support • win32ctypes.core.ctypes._resource • win32ctypes.core.ctypes._system_information • win32ctypes.core.ctypes._time

cv2 MissingModule

imported by: pygame._camera_opencv • pygame.camera

dataclasses SourceModule

imports: _thread • builtins • copy • functools • inspect • keyword • re • sys • types

imported by: packaging._tokenizer • pygame.examples.midi • setuptools._vendor.packaging._tokenizer

datetime SourceModule

imports: _datetime • _strptime • math • sys • time • warnings

imported by: _strptime • app.py • calendar • email.utils • http.cookiejar • http.server • setuptools._vendor.tomli._re • setuptools.warnings • test.libregrtest.main • test.support.testresult • win32ctypes.pywin32.pywintypes • xmlrpc.client

decimal SourceModule

imports: _decimal • _pydecimal

imported by: fractions • setuptools.config._validate_pyproject.fastjsonschema_validations • statistics • test.support • xmlrpc.client

difflib SourceModule

imports: collections • difflib • heapq • re • types

imported by: difflib • doctest • pygame.tests.run_tests__tests.run_tests__test • unittest.case

dis SourceModule

imports: argparse • collections • io • opcode • sys • types

imported by: PyInstaller.lib.modulegraph.util • inspect • pdb • setuptools.depends • trace

distutils Package

imports: distutils.archive_util • distutils.ccompiler • distutils.log • distutils.sysconfig • setuptools._distutils • sys

imported by: _osx_support • distutils._msvccompiler • distutils.archive_util • distutils.ccompiler • distutils.cmd • distutils.command • distutils.command.build_ext • distutils.command.sdist • distutils.config • distutils.core • distutils.debug • distutils.dep_util • distutils.dir_util • distutils.dist • distutils.errors • distutils.extension • distutils.fancy_getopt • distutils.file_util • distutils.filelist • distutils.log • distutils.spawn • distutils.sysconfig • distutils.text_file • distutils.util • distutils.version • distutils.versionpredicate • setuptools._distutils.command.build_ext • setuptools._distutils.command.sdist • setuptools._distutils.compilers.C.cygwin • setuptools._distutils.util • setuptools._shutil • setuptools.command.bdist_egg • setuptools.command.bdist_wheel • setuptools.command.egg_info • setuptools.command.sdist • setuptools.command.setopt • setuptools.discovery • setuptools.errors • setuptools.installer • setuptools.wheel • test.support

distutils._msvccompiler SourceModule

imports: distutils • distutils.ccompiler • distutils.errors • distutils.log • distutils.util • itertools • os • subprocess • winreg

imported by: distutils.command.build_ext

distutils.archive_util SourceModule

imports: distutils • distutils.dir_util • distutils.errors • distutils.log • distutils.spawn • grp • os • pwd • sys • tarfile • warnings • zipfile

imported by: distutils • distutils.cmd • distutils.command.sdist • setuptools._distutils.command.sdist

distutils.ccompiler SourceModule

imports: distutils • distutils.debug • distutils.dep_util • distutils.dir_util • distutils.errors • distutils.fancy_getopt • distutils.file_util • distutils.log • distutils.spawn • distutils.util • os • re • sys • tempfile

imported by: distutils • distutils._msvccompiler • distutils.command.build • distutils.command.build_ext • test.support

distutils.cmd SourceModule

imports: distutils • distutils.archive_util • distutils.debug • distutils.dep_util • distutils.dir_util • distutils.dist • distutils.errors • distutils.fancy_getopt • distutils.file_util • distutils.log • distutils.spawn • distutils.util • os • re • sys

imported by: distutils.config • distutils.core • distutils.dist • setuptools._distutils.dist • setuptools.dist

distutils.command Package

imports: distutils

imported by: distutils.command.bdist • distutils.command.build • distutils.command.build_ext • distutils.command.sdist • distutils.dist • setuptools._distutils.dist • setuptools.dist

distutils.command.bdist SourceModule

imports: distutils.command • distutils.core • distutils.errors • distutils.fancy_getopt • distutils.util • os

imported by: setuptools.command

distutils.command.build SourceModule

imports: distutils.ccompiler • distutils.command • distutils.core • distutils.errors • distutils.util • os • sys

imported by: setuptools.command.build

distutils.command.build_ext SourceModule

imports: concurrent.futures • contextlib • distutils • distutils._msvccompiler • distutils.ccompiler • distutils.command • distutils.core • distutils.dep_util • distutils.errors • distutils.extension • distutils.log • distutils.sysconfig • distutils.util • os • re • site • sys

imported by: setuptools

distutils.command.sdist SourceModule

imports: distutils • distutils.archive_util • distutils.command • distutils.core • distutils.dir_util • distutils.errors • distutils.fancy_getopt • distutils.file_util • distutils.filelist • distutils.log • distutils.text_file • distutils.util • glob • os • sys • warnings

imported by: setuptools.command.sdist

distutils.config SourceModule

imports: cgi • configparser • distutils • distutils.cmd • os

imported by: distutils.core

distutils.core SourceModule

imports: distutils • distutils.cmd • distutils.config • distutils.debug • distutils.dist • distutils.errors • distutils.extension • os • sys

imported by: distutils.command.bdist • distutils.command.build • distutils.command.build_ext • distutils.command.sdist • distutils.dist • setuptools • setuptools._distutils.dist • setuptools.dist • setuptools.extension

distutils.debug SourceModule

imports: distutils • os

imported by: distutils.ccompiler • distutils.cmd • distutils.core • distutils.dist • distutils.filelist • distutils.spawn • setuptools._distutils.cmd • setuptools._distutils.compilers.C.base • setuptools._distutils.filelist • setuptools.dist

distutils.dep_util SourceModule

imports: distutils • distutils.errors • os • stat

imported by: distutils.ccompiler • distutils.cmd • distutils.command.build_ext • distutils.file_util • distutils.util

distutils.dir_util SourceModule

imports: distutils • distutils.errors • distutils.file_util • distutils.log • errno • os

imported by: distutils.archive_util • distutils.ccompiler • distutils.cmd • distutils.command.sdist • distutils.util • setuptools._distutils.command.sdist • setuptools.command.bdist_egg

distutils.dist SourceModule

imports: configparser • distutils • distutils.cmd • distutils.command • distutils.core • distutils.debug • distutils.errors • distutils.fancy_getopt • distutils.log • distutils.util • distutils.versionpredicate • email • os • pprint • re • sys • warnings

imported by: distutils.cmd • distutils.core • setuptools._distutils.cmd • setuptools.config._apply_pyprojecttoml • setuptools.config.setupcfg • setuptools.dist

distutils.errors SourceModule

imports: distutils

imported by: distutils._msvccompiler • distutils.archive_util • distutils.ccompiler • distutils.cmd • distutils.command.bdist • distutils.command.build • distutils.command.build_ext • distutils.command.sdist • distutils.core • distutils.dep_util • distutils.dir_util • distutils.dist • distutils.fancy_getopt • distutils.file_util • distutils.filelist • distutils.spawn • distutils.sysconfig • distutils.util • setuptools.archive_util • setuptools.command.egg_info • setuptools.command.setopt • setuptools.config.expand • setuptools.dist • setuptools.errors • setuptools.extension • setuptools.installer • setuptools.msvc • test.support

distutils.extension SourceModule

imports: distutils • distutils.sysconfig • distutils.text_file • distutils.util • os • warnings

imported by: distutils.command.build_ext • distutils.core • setuptools.extension

distutils.fancy_getopt SourceModule

imports: distutils • distutils.errors • getopt • re • string • sys

imported by: distutils.ccompiler • distutils.cmd • distutils.command.bdist • distutils.command.sdist • distutils.dist • setuptools._distutils.cmd • setuptools._distutils.compilers.C.base • setuptools.dist

distutils.file_util SourceModule

imports: distutils • distutils.dep_util • distutils.errors • distutils.log • errno • os • os.path • stat

imported by: distutils.ccompiler • distutils.cmd • distutils.command.sdist • distutils.dir_util • distutils.util • setuptools._distutils.command.sdist

distutils.filelist SourceModule

imports: distutils • distutils.debug • distutils.errors • distutils.log • distutils.util • fnmatch • functools • os • re

imported by: distutils.command.sdist • distutils.util • setuptools.command.egg_info • setuptools.monkey

distutils.log SourceModule

imports: distutils • sys

imported by: _osx_support • distutils • distutils._msvccompiler • distutils.archive_util • distutils.ccompiler • distutils.cmd • distutils.command.build_ext • distutils.command.sdist • distutils.dir_util • distutils.dist • distutils.file_util • distutils.filelist • distutils.spawn • distutils.util • setuptools._shutil • setuptools.command.bdist_egg • setuptools.command.bdist_wheel • setuptools.command.egg_info • setuptools.command.sdist • setuptools.command.setopt • setuptools.discovery • setuptools.dist • setuptools.installer • setuptools.logging • setuptools.wheel

distutils.spawn SourceModule

imports: distutils • distutils.debug • distutils.errors • distutils.log • distutils.sysconfig • os • subprocess • sys

imported by: distutils.archive_util • distutils.ccompiler • distutils.cmd • distutils.util • setuptools._distutils.cmd • test.support

distutils.sysconfig SourceModule

imports: _imp • _osx_support • distutils • distutils.errors • distutils.text_file • os • re • sys • warnings

imported by: distutils • distutils.command.build_ext • distutils.extension • distutils.spawn • distutils.util • setuptools._distutils.command.build_ext • setuptools._distutils.compilers.C.cygwin • setuptools._distutils.extension • setuptools._distutils.util • test.support

distutils.text_file SourceModule

imports: distutils • io • sys

imported by: distutils.command.sdist • distutils.extension • distutils.sysconfig • setuptools._distutils.extension • setuptools._distutils.sysconfig

distutils.util SourceModule

imports: _aix_support • _osx_support • distutils • distutils.dep_util • distutils.dir_util • distutils.errors • distutils.file_util • distutils.filelist • distutils.log • distutils.spawn • distutils.sysconfig • importlib.util • os • pwd • py_compile • re • string • subprocess • sys • tempfile

imported by: distutils._msvccompiler • distutils.ccompiler • distutils.cmd • distutils.command.bdist • distutils.command.build • distutils.command.build_ext • distutils.command.sdist • distutils.dist • distutils.extension • distutils.filelist • setuptools._core_metadata • setuptools._distutils.compilers.C.unix • setuptools._distutils.extension • setuptools.command.egg_info • setuptools.command.setopt • setuptools.discovery • setuptools.dist • setuptools.wheel

distutils.version SourceModule

imports: distutils • re

imported by: distutils.versionpredicate

distutils.versionpredicate SourceModule

imports: distutils • distutils.version • operator • re

imported by: distutils.dist • setuptools._distutils.dist

doctest SourceModule

imports: __future__ • argparse • builtins • collections • difflib • inspect • io • linecache • os • pdb • re • sys • traceback • unittest

imported by: test.support

email Package

imports: email._header_value_parser • email.charset • email.errors • email.header • email.parser

imported by: distutils.dist • email._encoded_words • email._header_value_parser • email._parseaddr • email._policybase • email.base64mime • email.charset • email.contentmanager • email.encoders • email.errors • email.feedparser • email.generator • email.header • email.headerregistry • email.iterators • email.message • email.parser • email.policy • email.quoprimime • email.utils • importlib.metadata • importlib_metadata • setuptools._core_metadata • setuptools._distutils.dist • setuptools.wheel • urllib.request

email._encoded_words SourceModule

imports: base64 • binascii • email • email.errors • functools • re • string

imported by: email._header_value_parser • email.message

email._header_value_parser SourceModule

imports: email • email._encoded_words • email.errors • email.utils • operator • re • string • sys • urllib

imported by: email • email.headerregistry

email._parseaddr SourceModule

imports: calendar • email • time

imported by: email.utils

email._policybase SourceModule

imports: abc • email • email.charset • email.header • email.utils

imported by: email.feedparser • email.message • email.parser • email.policy

email.base64mime SourceModule

imports: base64 • binascii • email

imported by: email.charset • email.header

email.charset SourceModule

imports: email • email.base64mime • email.encoders • email.errors • email.quoprimime • functools

imported by: email • email._policybase • email.contentmanager • email.header • email.message • email.utils

email.contentmanager SourceModule

imports: binascii • email • email.charset • email.errors • email.message • email.quoprimime

imported by: email.policy

email.encoders SourceModule

imports: base64 • email • quopri

imported by: email.charset

email.errors SourceModule

imports: email

imported by: email • email._encoded_words • email._header_value_parser • email.charset • email.contentmanager • email.feedparser • email.header • email.headerregistry • email.message

email.feedparser SourceModule

imports: collections • email • email._policybase • email.errors • email.message • io • re

imported by: email.parser

email.generator SourceModule

imports: copy • email • email.utils • io • random • re • sys • time

imported by: email.message • setuptools.command.bdist_wheel

email.header SourceModule

imports: binascii • email • email.base64mime • email.charset • email.errors • email.quoprimime • re

imported by: email • email._policybase

email.headerregistry SourceModule

imports: email • email._header_value_parser • email.errors • email.utils • types

imported by: email.policy • setuptools.config._apply_pyprojecttoml

email.iterators SourceModule

imports: email • io • sys

imported by: email.message

email.message SourceModule

imports: email • email._encoded_words • email._policybase • email.charset • email.errors • email.generator • email.iterators • email.policy • email.utils • io • quopri • re • uu

imported by: cgi • email.contentmanager • email.feedparser • email.policy • http.client • importlib_metadata._adapters • pydoc • setuptools._core_metadata • setuptools.command.bdist_wheel • setuptools.config._validate_pyproject.formats

email.parser SourceModule

imports: email • email._policybase • email.feedparser • io

imported by: cgi • email • http.client

email.policy SourceModule

imports: email • email._policybase • email.contentmanager • email.headerregistry • email.message • email.utils • re • sys

imported by: email.message • importlib_metadata._adapters

email.quoprimime SourceModule

imports: email • re • string

imported by: email.charset • email.contentmanager • email.header

email.utils SourceModule

imports: datetime • email • email._parseaddr • email.charset • os • random • re • socket • time • urllib.parse

imported by: email._header_value_parser • email._policybase • email.generator • email.headerregistry • email.message • email.policy • http.server • urllib.request

encodings Package

imports: _winapi • codecs • encodings • encodings.aliases • encodings.ascii • encodings.base64_codec • encodings.big5 • encodings.big5hkscs • encodings.bz2_codec • encodings.charmap • encodings.cp037 • encodings.cp1006 • encodings.cp1026 • encodings.cp1125 • encodings.cp1140 • encodings.cp1250 • encodings.cp1251 • encodings.cp1252 • encodings.cp1253 • encodings.cp1254 • encodings.cp1255 • encodings.cp1256 • encodings.cp1257 • encodings.cp1258 • encodings.cp273 • encodings.cp424 • encodings.cp437 • encodings.cp500 • encodings.cp720 • encodings.cp737 • encodings.cp775 • encodings.cp850 • encodings.cp852 • encodings.cp855 • encodings.cp856 • encodings.cp857 • encodings.cp858 • encodings.cp860 • encodings.cp861 • encodings.cp862 • encodings.cp863 • encodings.cp864 • encodings.cp865 • encodings.cp866 • encodings.cp869 • encodings.cp874 • encodings.cp875 • encodings.cp932 • encodings.cp949 • encodings.cp950 • encodings.euc_jis_2004 • encodings.euc_jisx0213 • encodings.euc_jp • encodings.euc_kr • encodings.gb18030 • encodings.gb2312 • encodings.gbk • encodings.hex_codec • encodings.hp_roman8 • encodings.hz • encodings.idna • encodings.iso2022_jp • encodings.iso2022_jp_1 • encodings.iso2022_jp_2 • encodings.iso2022_jp_2004 • encodings.iso2022_jp_3 • encodings.iso2022_jp_ext • encodings.iso2022_kr • encodings.iso8859_1 • encodings.iso8859_10 • encodings.iso8859_11 • encodings.iso8859_13 • encodings.iso8859_14 • encodings.iso8859_15 • encodings.iso8859_16 • encodings.iso8859_2 • encodings.iso8859_3 • encodings.iso8859_4 • encodings.iso8859_5 • encodings.iso8859_6 • encodings.iso8859_7 • encodings.iso8859_8 • encodings.iso8859_9 • encodings.johab • encodings.koi8_r • encodings.koi8_t • encodings.koi8_u • encodings.kz1048 • encodings.latin_1 • encodings.mac_arabic • encodings.mac_croatian • encodings.mac_cyrillic • encodings.mac_farsi • encodings.mac_greek • encodings.mac_iceland • encodings.mac_latin2 • encodings.mac_roman • encodings.mac_romanian • encodings.mac_turkish • encodings.mbcs • encodings.oem • encodings.palmos • encodings.ptcp154 • encodings.punycode • encodings.quopri_codec • encodings.raw_unicode_escape • encodings.rot_13 • encodings.shift_jis • encodings.shift_jis_2004 • encodings.shift_jisx0213 • encodings.tis_620 • encodings.undefined • encodings.unicode_escape • encodings.utf_16 • encodings.utf_16_be • encodings.utf_16_le • encodings.utf_32 • encodings.utf_32_be • encodings.utf_32_le • encodings.utf_7 • encodings.utf_8 • encodings.utf_8_sig • encodings.uu_codec • encodings.zlib_codec • sys

imported by: app.py • codecs • encodings • encodings.aliases • encodings.ascii • encodings.base64_codec • encodings.big5 • encodings.big5hkscs • encodings.bz2_codec • encodings.charmap • encodings.cp037 • encodings.cp1006 • encodings.cp1026 • encodings.cp1125 • encodings.cp1140 • encodings.cp1250 • encodings.cp1251 • encodings.cp1252 • encodings.cp1253 • encodings.cp1254 • encodings.cp1255 • encodings.cp1256 • encodings.cp1257 • encodings.cp1258 • encodings.cp273 • encodings.cp424 • encodings.cp437 • encodings.cp500 • encodings.cp720 • encodings.cp737 • encodings.cp775 • encodings.cp850 • encodings.cp852 • encodings.cp855 • encodings.cp856 • encodings.cp857 • encodings.cp858 • encodings.cp860 • encodings.cp861 • encodings.cp862 • encodings.cp863 • encodings.cp864 • encodings.cp865 • encodings.cp866 • encodings.cp869 • encodings.cp874 • encodings.cp875 • encodings.cp932 • encodings.cp949 • encodings.cp950 • encodings.euc_jis_2004 • encodings.euc_jisx0213 • encodings.euc_jp • encodings.euc_kr • encodings.gb18030 • encodings.gb2312 • encodings.gbk • encodings.hex_codec • encodings.hp_roman8 • encodings.hz • encodings.idna • encodings.iso2022_jp • encodings.iso2022_jp_1 • encodings.iso2022_jp_2 • encodings.iso2022_jp_2004 • encodings.iso2022_jp_3 • encodings.iso2022_jp_ext • encodings.iso2022_kr • encodings.iso8859_1 • encodings.iso8859_10 • encodings.iso8859_11 • encodings.iso8859_13 • encodings.iso8859_14 • encodings.iso8859_15 • encodings.iso8859_16 • encodings.iso8859_2 • encodings.iso8859_3 • encodings.iso8859_4 • encodings.iso8859_5 • encodings.iso8859_6 • encodings.iso8859_7 • encodings.iso8859_8 • encodings.iso8859_9 • encodings.johab • encodings.koi8_r • encodings.koi8_t • encodings.koi8_u • encodings.kz1048 • encodings.latin_1 • encodings.mac_arabic • encodings.mac_croatian • encodings.mac_cyrillic • encodings.mac_farsi • encodings.mac_greek • encodings.mac_iceland • encodings.mac_latin2 • encodings.mac_roman • encodings.mac_romanian • encodings.mac_turkish • encodings.mbcs • encodings.oem • encodings.palmos • encodings.ptcp154 • encodings.punycode • encodings.quopri_codec • encodings.raw_unicode_escape • encodings.rot_13 • encodings.shift_jis • encodings.shift_jis_2004 • encodings.shift_jisx0213 • encodings.tis_620 • encodings.undefined • encodings.unicode_escape • encodings.utf_16 • encodings.utf_16_be • encodings.utf_16_le • encodings.utf_32 • encodings.utf_32_be • encodings.utf_32_le • encodings.utf_7 • encodings.utf_8 • encodings.utf_8_sig • encodings.uu_codec • encodings.zlib_codec • locale

encodings.aliases SourceModule

imports: encodings

imported by: app.py • encodings • locale

encodings.ascii SourceModule

imports: codecs • encodings

imported by: app.py • encodings

encodings.base64_codec SourceModule

imports: base64 • codecs • encodings

imported by: app.py • encodings

encodings.big5 SourceModule

imports: _codecs_tw • _multibytecodec • codecs • encodings

imported by: app.py • encodings

encodings.big5hkscs SourceModule

imports: _codecs_hk • _multibytecodec • codecs • encodings

imported by: app.py • encodings

encodings.bz2_codec SourceModule

imports: bz2 • codecs • encodings

imported by: app.py • encodings

encodings.charmap SourceModule

imports: codecs • encodings

imported by: app.py • encodings

encodings.cp037 SourceModule

imports: codecs • encodings

imported by: app.py • encodings

encodings.cp1006 SourceModule

imports: codecs • encodings

imported by: app.py • encodings

encodings.cp1026 SourceModule

imports: codecs • encodings

imported by: app.py • encodings

encodings.cp1125 SourceModule

imports: codecs • encodings

imported by: app.py • encodings

encodings.cp1140 SourceModule

imports: codecs • encodings

imported by: app.py • encodings

encodings.cp1250 SourceModule

imports: codecs • encodings

imported by: app.py • encodings

encodings.cp1251 SourceModule

imports: codecs • encodings

imported by: app.py • encodings

encodings.cp1252 SourceModule

imports: codecs • encodings

imported by: app.py • encodings

encodings.cp1253 SourceModule

imports: codecs • encodings

imported by: app.py • encodings

encodings.cp1254 SourceModule

imports: codecs • encodings

imported by: app.py • encodings

encodings.cp1255 SourceModule

imports: codecs • encodings

imported by: app.py • encodings

encodings.cp1256 SourceModule

imports: codecs • encodings

imported by: app.py • encodings

encodings.cp1257 SourceModule

imports: codecs • encodings

imported by: app.py • encodings

encodings.cp1258 SourceModule

imports: codecs • encodings

imported by: app.py • encodings

encodings.cp273 SourceModule

imports: codecs • encodings

imported by: app.py • encodings

encodings.cp424 SourceModule

imports: codecs • encodings

imported by: app.py • encodings

encodings.cp437 SourceModule

imports: codecs • encodings

imported by: app.py • encodings

encodings.cp500 SourceModule

imports: codecs • encodings

imported by: app.py • encodings

encodings.cp720 SourceModule

imports: codecs • encodings

imported by: app.py • encodings

encodings.cp737 SourceModule

imports: codecs • encodings

imported by: app.py • encodings

encodings.cp775 SourceModule

imports: codecs • encodings

imported by: app.py • encodings

encodings.cp850 SourceModule

imports: codecs • encodings

imported by: app.py • encodings

encodings.cp852 SourceModule

imports: codecs • encodings

imported by: app.py • encodings

encodings.cp855 SourceModule

imports: codecs • encodings

imported by: app.py • encodings

encodings.cp856 SourceModule

imports: codecs • encodings

imported by: app.py • encodings

encodings.cp857 SourceModule

imports: codecs • encodings

imported by: app.py • encodings

encodings.cp858 SourceModule

imports: codecs • encodings

imported by: app.py • encodings

encodings.cp860 SourceModule

imports: codecs • encodings

imported by: app.py • encodings

encodings.cp861 SourceModule

imports: codecs • encodings

imported by: app.py • encodings

encodings.cp862 SourceModule

imports: codecs • encodings

imported by: app.py • encodings

encodings.cp863 SourceModule

imports: codecs • encodings

imported by: app.py • encodings

encodings.cp864 SourceModule

imports: codecs • encodings

imported by: app.py • encodings

encodings.cp865 SourceModule

imports: codecs • encodings

imported by: app.py • encodings

encodings.cp866 SourceModule

imports: codecs • encodings

imported by: app.py • encodings

encodings.cp869 SourceModule

imports: codecs • encodings

imported by: app.py • encodings

encodings.cp874 SourceModule

imports: codecs • encodings

imported by: app.py • encodings

encodings.cp875 SourceModule

imports: codecs • encodings

imported by: app.py • encodings

encodings.cp932 SourceModule

imports: _codecs_jp • _multibytecodec • codecs • encodings

imported by: app.py • encodings

encodings.cp949 SourceModule

imports: _codecs_kr • _multibytecodec • codecs • encodings

imported by: app.py • encodings

encodings.cp950 SourceModule

imports: _codecs_tw • _multibytecodec • codecs • encodings

imported by: app.py • encodings

encodings.euc_jis_2004 SourceModule

imports: _codecs_jp • _multibytecodec • codecs • encodings

imported by: app.py • encodings

encodings.euc_jisx0213 SourceModule

imports: _codecs_jp • _multibytecodec • codecs • encodings

imported by: app.py • encodings

encodings.euc_jp SourceModule

imports: _codecs_jp • _multibytecodec • codecs • encodings

imported by: app.py • encodings

encodings.euc_kr SourceModule

imports: _codecs_kr • _multibytecodec • codecs • encodings

imported by: app.py • encodings

encodings.gb18030 SourceModule

imports: _codecs_cn • _multibytecodec • codecs • encodings

imported by: app.py • encodings

encodings.gb2312 SourceModule

imports: _codecs_cn • _multibytecodec • codecs • encodings

imported by: app.py • encodings

encodings.gbk SourceModule

imports: _codecs_cn • _multibytecodec • codecs • encodings

imported by: app.py • encodings

encodings.hex_codec SourceModule

imports: binascii • codecs • encodings

imported by: app.py • encodings

encodings.hp_roman8 SourceModule

imports: codecs • encodings

imported by: app.py • encodings

encodings.hz SourceModule

imports: _codecs_cn • _multibytecodec • codecs • encodings

imported by: app.py • encodings

encodings.idna SourceModule

imports: codecs • encodings • re • stringprep • unicodedata

imported by: app.py • encodings

encodings.iso2022_jp SourceModule

imports: _codecs_iso2022 • _multibytecodec • codecs • encodings

imported by: app.py • encodings

encodings.iso2022_jp_1 SourceModule

imports: _codecs_iso2022 • _multibytecodec • codecs • encodings

imported by: app.py • encodings

encodings.iso2022_jp_2 SourceModule

imports: _codecs_iso2022 • _multibytecodec • codecs • encodings

imported by: app.py • encodings

encodings.iso2022_jp_2004 SourceModule

imports: _codecs_iso2022 • _multibytecodec • codecs • encodings

imported by: app.py • encodings

encodings.iso2022_jp_3 SourceModule

imports: _codecs_iso2022 • _multibytecodec • codecs • encodings

imported by: app.py • encodings

encodings.iso2022_jp_ext SourceModule

imports: _codecs_iso2022 • _multibytecodec • codecs • encodings

imported by: app.py • encodings

encodings.iso2022_kr SourceModule

imports: _codecs_iso2022 • _multibytecodec • codecs • encodings

imported by: app.py • encodings

encodings.iso8859_1 SourceModule

imports: codecs • encodings

imported by: app.py • encodings

encodings.iso8859_10 SourceModule

imports: codecs • encodings

imported by: app.py • encodings

encodings.iso8859_11 SourceModule

imports: codecs • encodings

imported by: app.py • encodings

encodings.iso8859_13 SourceModule

imports: codecs • encodings

imported by: app.py • encodings

encodings.iso8859_14 SourceModule

imports: codecs • encodings

imported by: app.py • encodings

encodings.iso8859_15 SourceModule

imports: codecs • encodings

imported by: app.py • encodings

encodings.iso8859_16 SourceModule

imports: codecs • encodings

imported by: app.py • encodings

encodings.iso8859_2 SourceModule

imports: codecs • encodings

imported by: app.py • encodings

encodings.iso8859_3 SourceModule

imports: codecs • encodings

imported by: app.py • encodings

encodings.iso8859_4 SourceModule

imports: codecs • encodings

imported by: app.py • encodings

encodings.iso8859_5 SourceModule

imports: codecs • encodings

imported by: app.py • encodings

encodings.iso8859_6 SourceModule

imports: codecs • encodings

imported by: app.py • encodings

encodings.iso8859_7 SourceModule

imports: codecs • encodings

imported by: app.py • encodings

encodings.iso8859_8 SourceModule

imports: codecs • encodings

imported by: app.py • encodings

encodings.iso8859_9 SourceModule

imports: codecs • encodings

imported by: app.py • encodings

encodings.johab SourceModule

imports: _codecs_kr • _multibytecodec • codecs • encodings

imported by: app.py • encodings

encodings.koi8_r SourceModule

imports: codecs • encodings

imported by: app.py • encodings

encodings.koi8_t SourceModule

imports: codecs • encodings

imported by: app.py • encodings

encodings.koi8_u SourceModule

imports: codecs • encodings

imported by: app.py • encodings

encodings.kz1048 SourceModule

imports: codecs • encodings

imported by: app.py • encodings

encodings.latin_1 SourceModule

imports: codecs • encodings

imported by: app.py • encodings

encodings.mac_arabic SourceModule

imports: codecs • encodings

imported by: app.py • encodings

encodings.mac_croatian SourceModule

imports: codecs • encodings

imported by: app.py • encodings

encodings.mac_cyrillic SourceModule

imports: codecs • encodings

imported by: app.py • encodings

encodings.mac_farsi SourceModule

imports: codecs • encodings

imported by: app.py • encodings

encodings.mac_greek SourceModule

imports: codecs • encodings

imported by: app.py • encodings

encodings.mac_iceland SourceModule

imports: codecs • encodings

imported by: app.py • encodings

encodings.mac_latin2 SourceModule

imports: codecs • encodings

imported by: app.py • encodings

encodings.mac_roman SourceModule

imports: codecs • encodings

imported by: app.py • encodings

encodings.mac_romanian SourceModule

imports: codecs • encodings

imported by: app.py • encodings

encodings.mac_turkish SourceModule

imports: codecs • encodings

imported by: app.py • encodings

encodings.mbcs SourceModule

imports: codecs • encodings

imported by: app.py • encodings

encodings.oem SourceModule

imports: codecs • encodings

imported by: app.py • encodings

encodings.palmos SourceModule

imports: codecs • encodings

imported by: app.py • encodings

encodings.ptcp154 SourceModule

imports: codecs • encodings

imported by: app.py • encodings

encodings.punycode SourceModule

imports: codecs • encodings

imported by: app.py • encodings

encodings.quopri_codec SourceModule

imports: codecs • encodings • io • quopri

imported by: app.py • encodings

encodings.raw_unicode_escape SourceModule

imports: codecs • encodings

imported by: app.py • encodings

encodings.rot_13 SourceModule

imports: codecs • encodings • sys

imported by: app.py • encodings

encodings.shift_jis SourceModule

imports: _codecs_jp • _multibytecodec • codecs • encodings

imported by: app.py • encodings

encodings.shift_jis_2004 SourceModule

imports: _codecs_jp • _multibytecodec • codecs • encodings

imported by: app.py • encodings

encodings.shift_jisx0213 SourceModule

imports: _codecs_jp • _multibytecodec • codecs • encodings

imported by: app.py • encodings

encodings.tis_620 SourceModule

imports: codecs • encodings

imported by: app.py • encodings

encodings.undefined SourceModule

imports: codecs • encodings

imported by: app.py • encodings

encodings.unicode_escape SourceModule

imports: codecs • encodings

imported by: app.py • encodings

encodings.utf_16 SourceModule

imports: codecs • encodings • sys

imported by: app.py • encodings

encodings.utf_16_be SourceModule

imports: codecs • encodings

imported by: app.py • encodings

encodings.utf_16_le SourceModule

imports: codecs • encodings

imported by: app.py • encodings

encodings.utf_32 SourceModule

imports: codecs • encodings • sys

imported by: app.py • encodings

encodings.utf_32_be SourceModule

imports: codecs • encodings

imported by: app.py • encodings

encodings.utf_32_le SourceModule

imports: codecs • encodings

imported by: app.py • encodings

encodings.utf_7 SourceModule

imports: codecs • encodings

imported by: app.py • encodings

encodings.utf_8 SourceModule

imports: codecs • encodings

imported by: app.py • encodings

encodings.utf_8_sig SourceModule

imports: codecs • encodings

imported by: app.py • encodings

encodings.uu_codec SourceModule

imports: binascii • codecs • encodings • io

imported by: app.py • encodings

encodings.zlib_codec SourceModule

imports: codecs • encodings • zlib

imported by: app.py • encodings

enum SourceModule

imports: sys • types • warnings

imported by: app.py • ast • asyncio.constants • http • inspect • packaging._elffile • packaging.specifiers • py_compile • re • setuptools._vendor.packaging._elffile • signal • socket • ssl • tkinter • uuid

errno (builtin module)

imported by: PyInstaller.compat • asyncio.selector_events • asyncio.unix_events • asyncio.windows_events • distutils.dir_util • distutils.file_util • gettext • gzip • http.client • multiprocessing.forkserver • multiprocessing.queues • multiprocessing.shared_memory • pathlib • pygame.tests.test_utils.async_sub • serial.serialposix • setuptools._distutils.file_util • setuptools._vendor.jaraco.context • shutil • socket • ssl • subprocess • tempfile • test.support • xmlrpc.client

faulthandler (builtin module)

imported by: test.libregrtest.main • test.libregrtest.runtest • test.libregrtest.runtest_mp • test.libregrtest.setup • test.support

fcntl MissingModule

imported by: pygame.tests.test_utils.async_sub • serial.serialposix

fnmatch SourceModule

imports: functools • itertools • os • posixpath • re

imported by: PyInstaller.building.utils • PyInstaller.utils.hooks • PyInstaller.utils.hooks.conda • bdb • distutils.filelist • glob • pathlib • setuptools._distutils.filelist • setuptools.discovery • setuptools.glob • shutil • test.support • tkinter.filedialog • tracemalloc • unittest.loader • urllib.request

fractions SourceModule

imports: decimal • math • numbers • operator • re • sys

imported by: statistics

ftplib SourceModule

imports: netrc • re • socket • ssl • sys • warnings

imported by: urllib.request

functools SourceModule

imports: _functools • _thread • abc • collections • reprlib • types • typing • weakref

imported by: PyInstaller.isolated._parent • app.py • asyncio.base_events • asyncio.coroutines • asyncio.format_helpers • asyncio.selector_events • asyncio.tasks • asyncio.threads • concurrent.futures.process • configparser • contextlib • dataclasses • distutils.filelist • email._encoded_words • email.charset • fnmatch • http.server • importlib._common • importlib.metadata • importlib.util • importlib_metadata • importlib_metadata._functools • importlib_metadata._typing • inspect • linecache • locale • multiprocessing.reduction • multiprocessing.shared_memory • operator • packaging._manylinux • packaging._musllinux • packaging.specifiers • packaging.version • pathlib • pefile • pickle • pkgutil • platform • pygame.tests.pixelarray_test • pygame.tests.test_utils.buftools • pygame.tests.test_utils.png • re • setuptools • setuptools._discovery • setuptools._distutils._modified • setuptools._distutils.command._framework_compat • setuptools._distutils.command.install_data • setuptools._distutils.compat.py39 • setuptools._distutils.dir_util • setuptools._distutils.filelist • setuptools._distutils.sysconfig • setuptools._distutils.util • setuptools._entry_points • setuptools._reqs • setuptools._static • setuptools._vendor.jaraco.context • setuptools._vendor.jaraco.functools • setuptools._vendor.jaraco.text • setuptools._vendor.more_itertools.more • setuptools._vendor.more_itertools.recipes • setuptools._vendor.packaging._manylinux • setuptools._vendor.packaging._musllinux • setuptools._vendor.packaging.version • setuptools._vendor.tomli._re • setuptools.command.egg_info • setuptools.config • setuptools.config._apply_pyprojecttoml • setuptools.config._validate_pyproject • setuptools.config.pyprojecttoml • setuptools.config.setupcfg • setuptools.dist • setuptools.extension • setuptools.wheel • tempfile • test.libregrtest.runtest • test.support • test.support.testresult • threading • tracemalloc • types • typing • unittest.case • unittest.loader • unittest.mock • unittest.result • unittest.signals • zipp • zipp._functools • zipp.compat.py313

gc (builtin module)

imports: time

imported by: _posixsubprocess • pygame.tests.base_test • pygame.tests.bufferproxy_test • pygame.tests.font_test • pygame.tests.freetype_test • pygame.tests.pixelarray_test • pygame.tests.sprite_test • pygame.tests.surface_test • test.libregrtest.runtest • test.libregrtest.setup • test.support • trace • weakref

genericpath SourceModule

imports: os • stat

imported by: app.py • ntpath • posixpath

getopt SourceModule

imports: gettext • os • sys

imported by: base64 • distutils.fancy_getopt • mimetypes • pdb • pydoc • quopri • setuptools._distutils.fancy_getopt • webbrowser

getpass SourceModule

imports: contextlib • io • msvcrt • os • pwd • sys • termios • warnings

imported by: urllib.request

gettext SourceModule

imports: builtins • copy • errno • locale • os • re • struct • sys • warnings

imported by: argparse • getopt • optparse

glob SourceModule

imports: contextlib • fnmatch • os • re • sys

imported by: PyInstaller.building.utils • PyInstaller.utils.misc • distutils.command.sdist • pdb • pygame.tests.image_test • serial.tools.list_ports_common • serial.tools.list_ports_linux • serial.tools.list_ports_posix • setuptools._distutils.command.build_py • setuptools._distutils.command.sdist • setuptools.command.bdist_wheel • setuptools.config.expand • setuptools.discovery • setuptools.dist • setuptools.installer • test.libregrtest.main • test.support • webbrowser

grp MissingModule

imported by: distutils.archive_util • pathlib • setuptools._distutils.archive_util • shutil • subprocess • tarfile

gzip SourceModule

imports: _compression • argparse • builtins • errno • io • os • struct • sys • time • warnings • zlib

imported by: tarfile • test.support • xmlrpc.client

hashlib SourceModule

imports: _blake2 • _hashlib • _md5 • _sha1 • _sha256 • _sha3 • _sha512 • logging

imported by: PyInstaller.building.utils • hmac • pefile • pygame.tests.test_utils.png • random • setuptools._vendor.wheel.wheelfile • urllib.request • uuid

heapq SourceModule

imports: _heapq

imported by: app.py • asyncio.base_events • asyncio.queues • collections • difflib • queue • setuptools._vendor.more_itertools.more • setuptools._vendor.more_itertools.recipes

hmac SourceModule

imports: _hashlib • _operator • hashlib • warnings

imported by: multiprocessing.connection • secrets

html Package

imports: html.entities • re

imported by: cgi • html.entities • http.server

html.entities SourceModule

imports: html

imported by: html

http Package

imports: enum

imported by: http.client • http.cookiejar • http.server

http.client SourceModule

imports: collections.abc • email.message • email.parser • errno • http • io • re • socket • ssl • urllib.parse • warnings

imported by: http.cookiejar • http.server • urllib.request • xmlrpc.client

http.cookiejar SourceModule

imports: calendar • copy • datetime • http • http.client • io • logging • os • re • threading • time • traceback • urllib.parse • urllib.request • warnings

imported by: urllib.request

http.server SourceModule

imports: argparse • base64 • binascii • contextlib • copy • datetime • email.utils • functools • html • http • http.client • io • mimetypes • os • posixpath • pwd • select • shutil • socket • socketserver • subprocess • sys • time • urllib.parse

imported by: pydoc

importlib Package

imports: _frozen_importlib • _frozen_importlib_external • _imp • importlib • importlib._bootstrap • importlib._bootstrap_external • importlib._common • importlib.machinery • sys • types • warnings

imported by: PyInstaller.utils.hooks • _distutils_hack • importlib • importlib._bootstrap • importlib._bootstrap_external • importlib._common • importlib.abc • importlib.machinery • importlib.metadata • importlib.resources • importlib.util • importlib_metadata • inspect • pkgutil • serial • setuptools._distutils • setuptools._distutils._macos_compat • setuptools._distutils.unixccompiler • setuptools.config.expand • test.libregrtest.runtest • test.support • win32ctypes.core • zipp.compat.overlay

importlib._bootstrap SourceModule

imports: _frozen_importlib_external • importlib

imported by: importlib • importlib.abc • importlib.machinery • importlib.util • pydoc

importlib._bootstrap_external SourceModule

imports: _imp • _io • _warnings • importlib • importlib.metadata • marshal • nt • posix • sys • tokenize • winreg

imported by: PyInstaller.lib.modulegraph.modulegraph • importlib • importlib.abc • importlib.machinery • importlib.util • py_compile • pydoc

importlib._common SourceModule

imports: contextlib • functools • importlib • os • pathlib • tempfile • zipfile

imported by: importlib • importlib.resources

importlib.abc SourceModule

imports: _frozen_importlib • _frozen_importlib_external • abc • importlib • importlib._bootstrap • importlib._bootstrap_external • importlib.machinery • typing • warnings

imported by: _distutils_hack • importlib.metadata • importlib.resources • importlib.util • importlib_metadata • win32ctypes.core • zipimport

importlib.machinery SourceModule

imports: _imp • importlib • importlib._bootstrap • importlib._bootstrap_external

imported by: PyInstaller.compat • PyInstaller.lib.modulegraph.modulegraph • ctypes.util • importlib • importlib.abc • inspect • packaging.tags • pkgutil • py_compile • pydoc • runpy • setuptools._imp • setuptools._vendor.packaging.tags • setuptools.config.expand

importlib.metadata SourceModule

imports: abc • collections • configparser • contextlib • csv • email • functools • importlib • importlib.abc • io • itertools • operator • os • pathlib • pep517 • posixpath • re • sys • zipfile

imported by: PyInstaller.compat • PyInstaller.lib.modulegraph.modulegraph • PyInstaller.utils.hooks.conda • importlib._bootstrap_external • setuptools._importlib

importlib.resources SourceModule

imports: 'typing.io' • contextlib • importlib • importlib._common • importlib.abc • io • os • pathlib • types • typing

imported by: setuptools._importlib • setuptools._vendor.jaraco.text

importlib.util SourceModule

imports: _imp • contextlib • functools • importlib • importlib._bootstrap • importlib._bootstrap_external • importlib.abc • sys • types • warnings

imported by: PyInstaller.compat • PyInstaller.lib.modulegraph.modulegraph • PyInstaller.utils.hooks • _distutils_hack • distutils.util • pkgutil • py_compile • pydoc • runpy • setuptools._distutils.command.build_py • setuptools._distutils.command.install_lib • setuptools._distutils.util • setuptools._imp • test.support • zipfile

importlib_metadata Package

imports: __future__ • abc • collections • collections.abc • contextlib • csv • email • functools • importlib • importlib.abc • importlib_metadata • importlib_metadata._adapters • importlib_metadata._collections • importlib_metadata._compat • importlib_metadata._functools • importlib_metadata._itertools • importlib_metadata._meta • importlib_metadata._typing • importlib_metadata.compat • importlib_metadata.compat.py311 • importlib_metadata.compat.py39 • inspect • itertools • json • operator • os • pathlib • posixpath • re • sys • textwrap • types • typing • zipp.compat.overlay

imported by: PyInstaller.compat • PyInstaller.lib.modulegraph.modulegraph • importlib_metadata • importlib_metadata._adapters • importlib_metadata._collections • importlib_metadata._compat • importlib_metadata._functools • importlib_metadata._itertools • importlib_metadata._meta • importlib_metadata._text • importlib_metadata._typing • importlib_metadata.compat • importlib_metadata.compat.py39 • setuptools._importlib

importlib_metadata._adapters SourceModule

imports: email.message • email.policy • importlib_metadata • importlib_metadata._text • re • textwrap

imported by: importlib_metadata

importlib_metadata._collections SourceModule

imports: collections • importlib_metadata • typing

imported by: importlib_metadata

importlib_metadata._compat SourceModule

imports: importlib_metadata • platform • sys

imported by: importlib_metadata

importlib_metadata._functools SourceModule

imports: functools • importlib_metadata • types • typing

imported by: importlib_metadata • importlib_metadata._text

importlib_metadata._itertools SourceModule

imports: collections • importlib_metadata • itertools

imported by: importlib_metadata

importlib_metadata._meta SourceModule

imports: __future__ • collections.abc • importlib_metadata • os • typing

imported by: importlib_metadata • importlib_metadata._typing

importlib_metadata._text SourceModule

imports: importlib_metadata • importlib_metadata._functools • re

imported by: importlib_metadata._adapters

importlib_metadata._typing SourceModule

imports: functools • importlib_metadata • importlib_metadata._meta • typing

imported by: importlib_metadata • importlib_metadata.compat.py39

importlib_metadata.compat Package

imports: importlib_metadata • importlib_metadata.compat.py311 • importlib_metadata.compat.py39

imported by: importlib_metadata • importlib_metadata.compat.py311 • importlib_metadata.compat.py39

importlib_metadata.compat.py311 SourceModule

imports: importlib_metadata.compat • os • pathlib • sys • types

imported by: importlib_metadata • importlib_metadata.compat

importlib_metadata.compat.py39 SourceModule

imports: __future__ • importlib_metadata • importlib_metadata._typing • importlib_metadata.compat • typing

imported by: importlib_metadata • importlib_metadata.compat

importlib_resources MissingModule

imported by: setuptools._vendor.jaraco.text

inspect SourceModule

imports: abc • argparse • ast • builtins • collections • collections.abc • dis • enum • functools • importlib • importlib.machinery • itertools • linecache • operator • os • re • sys • token • tokenize • types • warnings

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

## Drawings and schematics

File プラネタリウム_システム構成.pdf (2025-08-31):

# システム構成(2024)

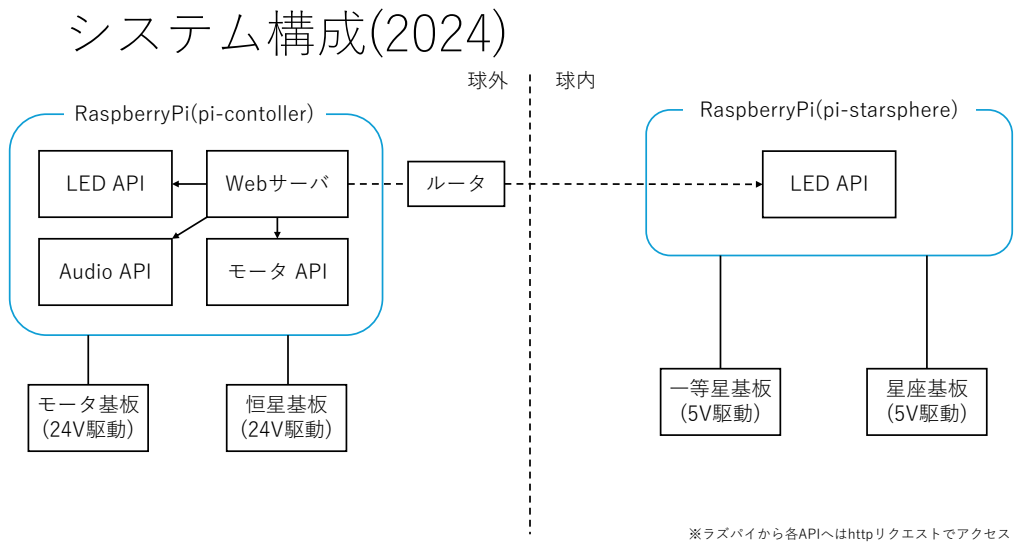
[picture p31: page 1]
RaspberryPi(pi-contoller); RaspberryPi(pi-starsphere); 一等星基板 (5V駆動); 星座基板; モータ基板; (5V駆動); (24V駆動); 恒星基板 (24V駆動); LED API; Webサーバ; Audio API; モータ API; ルータ; ※ラズパイから各APIへはhttpリクエストでアクセス

# システム構成(2025)

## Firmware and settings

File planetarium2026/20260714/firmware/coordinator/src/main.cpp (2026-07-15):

#include <Arduino.h>
#include <WiFi.h>
#include <esp_now.h>
#include <esp_wifi.h>
#include <ArduinoJson.h>
#include <driver/gpio.h>
#include <esp_rom_sys.h>
#include <math.h>
#include "protocol.h"

using namespace Plane;

// motor_driver_回路図.pdf / XIAO ESP32C3 D0..D10 pin assignment
constexpr uint8_t PIN_MO = D0;       // SLA7078 MO (monitor input)
constexpr uint8_t PIN_M2 = D1;
constexpr uint8_t PIN_CLOCK = D2;
constexpr uint8_t PIN_DIRECTION = D3;
constexpr uint8_t PIN_FLAG = D4;     // SLA7078 FLAG input
constexpr uint8_t PIN_SYNC = D5;
constexpr uint8_t PIN_RESET = D6;
constexpr uint8_t PIN_M3 = D7;
constexpr uint8_t PIN_M1 = D8;
constexpr uint8_t PIN_DRIVER_SLEEP = D9;  // ref/sleep_mcu PMOS control
constexpr uint8_t PIN_STATUS_LED = D10;

#ifndef MOTOR_FULL_STEPS_PER_REV
#define MOTOR_FULL_STEPS_PER_REV 200
#endif
#ifndef MOTOR_MICROSTEPS
#define MOTOR_MICROSTEPS 1
#endif
#ifndef MOTOR_DIRECTION_INVERT
#define MOTOR_DIRECTION_INVERT 0
#endif
#ifndef MOTOR_MAX_OUTPUT_SPEED_DEG_SEC
#define MOTOR_MAX_OUTPUT_SPEED_DEG_SEC 300
#endif

constexpr float STEPS_PER_DEGREE =
    (MOTOR_FULL_STEPS_PER_REV * MOTOR_MICROSTEPS) / 360.0f;
constexpr uint32_t MOTOR_TIMER_HZ = 40000;
constexpr float CONTINUOUS_CW_COMMAND_DEG = 999.0f;
constexpr float CONTINUOUS_CCW_COMMAND_DEG = -999.0f;

struct LightLink {
  bool online = false;
  bool unstable = false;
  bool awaiting = false;
  uint8_t retries = 0;
  uint32_t sentAt = 0;
  uint32_t lastAck = 0;
  uint32_t pendingSeq = 0;
  uint32_t remoteUptime = 0;
} light;

MotorPayload motorSet{};
LightPayload lightSet{};
uint32_t sequence = 0;
uint32_t lastPeriodic = 0;
uint32_t espInterval = 10000;
uint32_t retryTimeout = 500;
uint8_t maxRetries = 5;
uint32_t pcCommunicationTimeoutMs = 22000;
uint32_t lastPcPacketAt = 0;
bool pcSafetyStopActive = true;
String line;

volatile int64_t physicalSteps = 0;
volatile int64_t zeroOffsetSteps = 0;
volatile int64_t targetSteps = 0;
volatile uint32_t stepRateMilliHz = 0;
volatile uint32_t stepPhase = 0;
volatile int8_t jogDirection = 0;  // -1: CCW, +1: CW, 0: position mode
portMUX_TYPE motorMux = portMUX_INITIALIZER_UNLOCKED;
hw_timer_t *motorTimer = nullptr;
float commandedSpeedDegSec = 0.0f;
uint32_t motorLastApplied = 0;
bool motorCalibrationMode = false;
bool motorOriginSet = false;
bool originWarningSent = false;
bool emergencyStopActive = false;
TaskHandle_t communicationTaskHandle = nullptr;
void communicationTask(void *parameter);
void sendLight(bool retry = false);

float normalizeAngle(float angleDeg) {
  float wrapped = fmodf(angleDeg, 360.0f);
  return wrapped < 0 ? wrapped + 360.0f : wrapped;
}

float currentAngleDeg() {
  portENTER_CRITICAL(&motorMux);
  int64_t position = physicalSteps;
  int64_t zero = zeroOffsetSteps;
  portEXIT_CRITICAL(&motorMux);
  return normalizeAngle((position - zero) / STEPS_PER_DEGREE);
}

void jsonEvent(const char *event, const char *device = "") {
  JsonDocument d;
  d["type"] = "event";
  d["event"] = event;
  if (*device) {
    d["device"] = device;
  }
  serializeJson(d, Serial);
  Serial.println();
}

void IRAM_ATTR onMotorTimer() {
  portENTER_CRITICAL_ISR(&motorMux);
  int8_t direction = jogDirection;
  if (direction == 0) {
    if (physicalSteps < targetSteps) {
      direction = 1;
    } else if (physicalSteps > targetSteps) {
      direction = -1;
    }
    else {
      stepPhase = 0;
      portEXIT_CRITICAL_ISR(&motorMux);
      return;
    }
  }
  stepPhase += stepRateMilliHz;
  constexpr uint32_t PHASE_LIMIT = MOTOR_TIMER_HZ * 1000UL;
  if (stepRateMilliHz && stepPhase >= PHASE_LIMIT) {
    stepPhase -= PHASE_LIMIT;
    bool cw = direction > 0;
    gpio_set_level((gpio_num_t)PIN_DIRECTION,
                   (cw ^ MOTOR_DIRECTION_INVERT) ? 0 : 1);
    esp_rom_delay_us(1);  // CW/CCW setup time before CLOCK
    gpio_set_level((gpio_num_t)PIN_CLOCK, 1);
    esp_rom_delay_us(2);  // SLA7078 minimum CLOCK high width
    gpio_set_level((gpio_num_t)PIN_CLOCK, 0);
    physicalSteps += direction;
  }
  portEXIT_CRITICAL_ISR(&motorMux);
}

void updateStepRate(float speedDegSec) {
  uint32_t rate = (uint32_t)llroundf(speedDegSec * STEPS_PER_DEGREE * 1000.0f);
  portENTER_CRITICAL(&motorMux);
  stepRateMilliHz = rate;
  portEXIT_CRITICAL(&motorMux);
}

void applyMotorTarget(float angleDeg, float speedDegSec) {
  if (!motorOriginSet) {
    if (!originWarningSent) {
      jsonEvent("motor_command_blocked_origin_unset", "motor");
      originWarningSent = true;
    }
    return;
  }
  const bool continuousCw =
      fabsf(angleDeg - CONTINUOUS_CW_COMMAND_DEG) < 0.001f;
  const bool continuousCcw =
      fabsf(angleDeg - CONTINUOUS_CCW_COMMAND_DEG) < 0.001f;
  const bool continuous = continuousCw || continuousCcw;
  const float normalizedTarget = continuousCw
                                     ? CONTINUOUS_CW_COMMAND_DEG
                                 : continuousCcw
                                     ? CONTINUOUS_CCW_COMMAND_DEG
                                     : normalizeAngle(angleDeg);
  motorSet.angleDeg = normalizedTarget;
  motorSet.speedDegSec = min(fabsf(speedDegSec),
                             (float)MOTOR_MAX_OUTPUT_SPEED_DEG_SEC);
  commandedSpeedDegSec = motorSet.speedDegSec;
  portENTER_CRITICAL(&motorMux);
  if (continuous) {
    // +999/-999 are command values, not physical target angles.
    jogDirection = continuousCw ? 1 : -1;
    targetSteps = physicalSteps;
  } else {
    jogDirection = 0;
    const int64_t revolutionSteps = llroundf(360.0f * STEPS_PER_DEGREE);
    int64_t logicalSteps = physicalSteps - zeroOffsetSteps;
    int64_t currentWithinRevolution = logicalSteps % revolutionSteps;
    if (currentWithinRevolution < 0) {
      currentWithinRevolution += revolutionSteps;
    }
    int64_t requestedWithinRevolution =
        llroundf(normalizedTarget * STEPS_PER_DEGREE) % revolutionSteps;
    int64_t delta = requestedWithinRevolution - currentWithinRevolution;
    if (delta > revolutionSteps / 2) {
      delta -= revolutionSteps;
    }
    if (delta < -revolutionSteps / 2) {
      delta += revolutionSteps;
    }
    targetSteps = physicalSteps + delta;
  }
  portEXIT_CRITICAL(&motorMux);
  updateStepRate(commandedSpeedDegSec);
  motorLastApplied = millis();
}

void stopMotorImmediatelyForPcLoss() {
  portENTER_CRITICAL(&motorMux);
  jogDirection = 0;
  targetSteps = physicalSteps;
  stepRateMilliHz = 0;
  stepPhase = 0;
  portEXIT_CRITICAL(&motorMux);
  commandedSpeedDegSec = 0.0f;
  motorSet.speedDegSec = 0.0f;
  motorCalibrationMode = false;
  motorLastApplied = millis();
}

void activateEmergencyStop() {
  emergencyStopActive = true;
  stopMotorImmediatelyForPcLoss();
  lightSet.firstStar = 0;
  lightSet.stars = 0;
  lightSet.patterns = 0;
  lightSet.fade = 0;
  sendLight();
  jsonEvent("emergency_stop_activated", "system");
}

void updatePcSafetyWatchdog() {
  const bool timedOut = lastPcPacketAt == 0 ||
                        millis() - lastPcPacketAt > pcCommunicationTimeoutMs;
  if (timedOut && !pcSafetyStopActive) {
    pcSafetyStopActive = true;
    stopMotorImmediatelyForPcLoss();
    jsonEvent("pc_communication_lost_motor_stopped", "motor");
  }
}

void applyMotorCalibration(const char *action, float speedDegSec,
                           float valueDeg) {
  commandedSpeedDegSec = min(fabsf(speedDegSec),
                              (float)MOTOR_MAX_OUTPUT_SPEED_DEG_SEC);
  updateStepRate(commandedSpeedDegSec);
  portENTER_CRITICAL(&motorMux);
  if (!strcmp(action, "jog_cw")) {
    jogDirection = 1;
  } else if (!strcmp(action, "jog_ccw")) {
    jogDirection = -1;
  } else if (!strcmp(action, "stop")) {
    jogDirection = 0;
    targetSteps = physicalSteps;
    commandedSpeedDegSec = 0;
    stepRateMilliHz = 0;
  } else if (!strcmp(action, "move_relative")) {
    jogDirection = 0;
    targetSteps = physicalSteps + llroundf(valueDeg * STEPS_PER_DEGREE);
  } else if (!strcmp(action, "set_zero")) {
    jogDirection = 0;
    targetSteps = physicalSteps;
    zeroOffsetSteps = physicalSteps;
    commandedSpeedDegSec = 0;
    stepRateMilliHz = 0;
    motorOriginSet = true;
    originWarningSent = false;
  } else if (!strcmp(action, "set_angle")) {
    jogDirection = 0;
    targetSteps = physicalSteps;
    zeroOffsetSteps = physicalSteps -
                      llroundf(normalizeAngle(valueDeg) * STEPS_PER_DEGREE);
    commandedSpeedDegSec = 0;
    stepRateMilliHz = 0;
    motorOriginSet = true;
    originWarningSent = false;
  }
  portEXIT_CRITICAL(&motorMux);
  motorLastApplied = millis();
  if (motorOriginSet &&
      (!strcmp(action, "set_zero") || !strcmp(action, "set_angle"))) {
    jsonEvent("motor_origin_set", "motor");
  }
}

void sendLight(bool retry) {
  lightSet.heartbeatTimeoutMs = max((uint32_t)3000, espInterval * 2 + 2000);
  lightSet.h = header(Type::LIGHT_SET, sizeof(lightSet),
                      retry ? light.pendingSeq : ++sequence);
  light.pendingSeq = lightSet.h.seq;
  esp_now_send(MAC_LIGHT, reinterpret_cast<uint8_t *>(&lightSet),
               sizeof(lightSet));
  light.awaiting = true;
  light.sentAt = millis();
  if (!retry) {
    light.retries = 0;
  }
}

void emitStatus() {
  JsonDocument d;
  d["type"] = "status";
  d["uptime_ms"] = millis();
  d["motor_calibration_mode"] = motorCalibrationMode;
  d["motor_origin_set"] = motorOriginSet;
  d["emergency_stop"] = emergencyStopActive;
  d["pc_safety_stop"] = pcSafetyStopActive;
  d["pc_timeout_ms"] = pcCommunicationTimeoutMs;
  auto mlink = d["motor"].to<JsonObject>();
  mlink["online"] = true;
  mlink["unstable"] = false;
  // The motor driver is on this MCU, so every status cycle is a local heartbeat.
  mlink["last_ack_ms"] = millis();
  mlink["retries"] = 0;
  auto llink = d["light"].to<JsonObject>();
  llink["online"] = light.online;
  llink["unstable"] = light.unstable;
  llink["last_ack_ms"] = light.lastAck;
  llink["uptime_ms"] = light.remoteUptime;
  llink["retries"] = light.retries;
  auto m = d["actual"]["motor"].to<JsonObject>();
  int8_t motionJog;
  int64_t motionPhysical, motionTarget, motionZero;
  portENTER_CRITICAL(&motorMux);
  motionJog = jogDirection;
  motionPhysical = physicalSteps;
  motionTarget = targetSteps;
  motionZero = zeroOffsetSteps;
  portEXIT_CRITICAL(&motorMux);
  m["angle"] = currentAngleDeg();
  // Calibration jog reports a signed speed: CW positive, CCW negative.
  m["speed"] = motorCalibrationMode && motionJog < 0
                   ? -commandedSpeedDegSec
                   : commandedSpeedDegSec;
  bool relativeMoving = motorCalibrationMode && motionJog == 0 &&
                        motionPhysical != motionTarget && stepRateMilliHz > 0;
  m["motion"] = motionJog > 0 ? "jog_cw"
                  : motionJog < 0 ? "jog_ccw"
                  : relativeMoving ? "relative"
                                   : "stopped";
  m["target_angle"] = normalizeAngle(
      (motionTarget - motionZero) / STEPS_PER_DEGREE);
  m["continuous_cw"] =
      fabsf(motorSet.angleDeg - CONTINUOUS_CW_COMMAND_DEG) < 0.001f;
  m["continuous_ccw"] =
      fabsf(motorSet.angleDeg - CONTINUOUS_CCW_COMMAND_DEG) < 0.001f;
  auto q = d["actual"]["light"].to<JsonObject>();
  q["first"] = lightSet.firstStar;
  q["stars"] = lightSet.stars;
  q["patterns"] = lightSet.patterns;
  d["motor_driver_flag"] = digitalRead(PIN_FLAG) == HIGH ? "active" : "normal";
  d["cores"]["communication"] = 0;
  d["cores"]["motor"] = 0;
  serializeJson(d, Serial);
  Serial.println();
}

void onReceive(const uint8_t *, const uint8_t *data, int len) {
  if (len != static_cast<int>(sizeof(AckPayload))) {
    return;
  }
  AckPayload a;
  memcpy(&a, data, sizeof(a));
  if (!valid(a.h, len) || a.h.type != Type::LIGHT_ACK ||
      a.h.seq != light.pendingSeq) {
    return;
  }
  bool recovered = !light.online || light.unstable;
  light.online = true;
  light.unstable = false;
  light.awaiting = false;
  light.lastAck = millis();
  light.remoteUptime = a.uptimeMs;
  lightSet.firstStar = a.firstStar;
  lightSet.stars = a.stars;
  lightSet.patterns = a.patterns;
  if (recovered) {
    jsonEvent("communication_recovered", "light");
  }
}

void handleLine() {
  JsonDocument d;
  if (deserializeJson(d, line)) {
    jsonEvent("invalid_json");
    return;
  }
  const bool recovered = pcSafetyStopActive;
  lastPcPacketAt = millis();
  pcSafetyStopActive = false;
  if (recovered) {
    jsonEvent("pc_communication_recovered", "motor");
  }
  const char *cmd = d["cmd"] | "";
  if (!strcmp(cmd, "emergency_stop")) {
    activateEmergencyStop();
  } else if (!strcmp(cmd, "emergency_stop_release")) {
    emergencyStopActive = false;
    stopMotorImmediatelyForPcLoss();
    jsonEvent("emergency_stop_released", "system");
  } else if (!strcmp(cmd, "set")) {
    if (emergencyStopActive) {
      stopMotorImmediatelyForPcLoss();
      if (lightSet.firstStar || lightSet.stars || lightSet.patterns) {
        lightSet.firstStar = 0;
        lightSet.stars = 0;
        lightSet.patterns = 0;
        lightSet.fade = 0;
        sendLight();
      }
      jsonEvent("command_blocked_emergency_stop", "system");
      return;
    }
    float angle = d["motor"]["angle"] | motorSet.angleDeg;
    float speed = d["motor"]["speed"] | motorSet.speedDegSec;
    if (!motorCalibrationMode) {
      applyMotorTarget(angle, speed);
    }
    lightSet.firstStar = d["light"]["first"] | false;
    lightSet.stars = d["light"]["stars"] | false;
    lightSet.patterns = 0;
    for (int i = 0; i < 8; ++i) {
      if (d["light"]["patterns"][i] | false) {
        lightSet.patterns |= 1 << i;
      }
    }
    lightSet.fade = d["light"]["fade"] | false;
    sendLight();
  } else if (!strcmp(cmd, "config")) {
    espInterval = constrain((uint32_t)(d["esp_interval_ms"] | espInterval),
                            100, 3600000);
    retryTimeout = constrain((uint32_t)(d["retry_timeout_ms"] | retryTimeout),
                             100, 10000);
    maxRetries = constrain((uint8_t)(d["max_retries"] | maxRetries), 1, 10);
    pcCommunicationTimeoutMs = constrain(
        (uint32_t)(d["pc_timeout_ms"] | pcCommunicationTimeoutMs),
        3000, 3600000);
  } else if (!strcmp(cmd, "motor_cal")) {
    if (emergencyStopActive) {
      stopMotorImmediatelyForPcLoss();
      jsonEvent("motor_calibration_blocked_emergency_stop", "motor");
      return;
    }
    const char *action = d["action"] | "";
    if (!strcmp(action, "exit")) {
      motorCalibrationMode = false;
      portENTER_CRITICAL(&motorMux);
      jogDirection = 0;
      targetSteps = physicalSteps;
      stepRateMilliHz = 0;
      portEXIT_CRITICAL(&motorMux);
      commandedSpeedDegSec = 0;
      jsonEvent("motor_calibration_finished", "motor");
    } else {
      motorCalibrationMode = true;
      applyMotorCalibration(action, d["speed"] | 0.0f, d["value"] | 0.0f);
      jsonEvent("motor_calibration_command", "motor");
    }
  } else if (!strcmp(cmd, "send_now")) {
    sendLight();
    motorLastApplied = millis();
  } else if (!strcmp(cmd, "ping")) {
    Serial.println("{\"type\":\"pong\"}");
  }
}

void retryLight() {
  if (!light.awaiting || millis() - light.sentAt < retryTimeout) {
    return;
  }
  if (light.retries < maxRetries) {
    ++light.retries;
    light.unstable = true;
    light.online = true;
    jsonEvent("communication_unstable", "light");
    sendLight(true);
  } else {
    light.awaiting = false;
    light.online = false;
    light.unstable = false;
    jsonEvent("communication_lost", "light");
  }
}

void setupMotorHardware() {
  pinMode(PIN_MO, INPUT);
  pinMode(PIN_FLAG, INPUT);  // 10 kΩ external pull-down on the circuit board
  pinMode(PIN_M1, OUTPUT);
  pinMode(PIN_M2, OUTPUT);
  pinMode(PIN_M3, OUTPUT);
  pinMode(PIN_DIRECTION, OUTPUT);
  pinMode(PIN_SYNC, OUTPUT);
  pinMode(PIN_STATUS_LED, OUTPUT);
  pinMode(PIN_DRIVER_SLEEP, OUTPUT);
  pinMode(PIN_RESET, OUTPUT);
  pinMode(PIN_CLOCK, OUTPUT);
  digitalWrite(PIN_CLOCK, LOW);
  digitalWrite(PIN_M1, LOW);
  digitalWrite(PIN_M2, LOW);
  digitalWrite(PIN_M3, LOW);
  digitalWrite(PIN_SYNC, LOW);
  // LOW turns the PMOS on and raises Ref/Sleep1 into the Sleep1 range.
  // Keep it HIGH for normal operation (PMOS off).
  digitalWrite(PIN_DRIVER_SLEEP, HIGH);
  delayMicroseconds(100);  // Datasheet minimum wake-up time before CLOCK.
  // SLA7078 RESET is active-high. Reset once, then keep LOW for operation.
  digitalWrite(PIN_RESET, HIGH);
  delayMicroseconds(5);
  digitalWrite(PIN_RESET, LOW);
  delayMicroseconds(10);
  digitalWrite(PIN_STATUS_LED, HIGH);
  motorTimer = timerBegin(0, 80, true);  // 1 MHz timer clock
  timerAttachInterrupt(motorTimer, &onMotorTimer, true);
  timerAlarmWrite(motorTimer, 1000000UL / MOTOR_TIMER_HZ, true);
  timerAlarmEnable(motorTimer);
  motorLastApplied = millis();
}

void setup() {
  Serial.begin(115200);
  setupMotorHardware();
  WiFi.mode(WIFI_STA);
  esp_wifi_set_mac(WIFI_IF_STA, MAC_COORD);
  esp_wifi_set_channel(CHANNEL, WIFI_SECOND_CHAN_NONE);
  if (esp_now_init() != ESP_OK) {
    jsonEvent("esp_now_init_failed");
    return;
  }
  esp_now_register_recv_cb(onReceive);
  esp_now_peer_info_t peer{};
  memcpy(peer.peer_addr, MAC_LIGHT, 6);
  peer.channel = CHANNEL;
  peer.encrypt = false;
  esp_now_add_peer(&peer);
  Serial.println("{\"type\":\"hello\",\"device\":\"coordinator_motor\",\"protocol\":1}");
  sendLight();
  // ESP32C3 has one CPU core. Communication runs as a normal FreeRTOS task,
  // while motor CLOCK generation remains isolated in the hardware timer ISR.
  xTaskCreate(communicationTask, "communication", 8192, nullptr, 2,
              &communicationTaskHandle);
}

void communicationTask(void *) {
  for (;;) {
    while (Serial.available()) {
      char c = Serial.read();
      if (c == '\n') {
        handleLine();
        line = "";
      } else if (c != '\r' && line.length() < 1024) {
        line += c;
      }
    }
    if (millis() - lastPeriodic >= espInterval) {
      sendLight();
      lastPeriodic = millis();
    }
    retryLight();
    updatePcSafetyWatchdog();
    static uint32_t lastStatus = 0;
    if (millis() - lastStatus >= 250) {
      lastStatus = millis();
      emitStatus();
    }
    vTaskDelay(pdMS_TO_TICKS(1));
  }
}

void loop() {
  // The communication task handles application work. Motor CLOCK generation
  // is independent of task scheduling because it runs in the timer ISR.
  delay(1000);
}

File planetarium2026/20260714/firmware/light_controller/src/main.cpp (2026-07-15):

#include <Arduino.h>
#include <WiFi.h>
#include <esp_now.h>
#include <esp_wifi.h>

#include "protocol.h"

using namespace Plane;

// seiza_ittose_回路図.pdf / XIAO ESP32C3 pin assignment.
// The TC5626B3A inputs drive constellation outputs 1..8.
constexpr uint8_t CONSTELLATION_PINS[8] = {
    D7, D8, D9, D10, D5, D4, D3, D2,
};
constexpr uint8_t STARS_PIN = D0;
constexpr uint8_t FIRST_STAR_PIN = D1;
constexpr uint8_t STATUS_LED_PIN = D6;
constexpr bool STARS_ACTIVE_HIGH = false;
constexpr bool FIRST_STAR_ACTIVE_HIGH = true;
constexpr bool CONSTELLATIONS_ACTIVE_HIGH = true;

constexpr uint32_t DEFAULT_HEARTBEAT_TIMEOUT_MS = 22000;
constexpr uint32_t MIN_HEARTBEAT_TIMEOUT_MS = 3000;
constexpr uint32_t CONNECTED_BLINK_INTERVAL_MS = 1000;
constexpr uint32_t DISCONNECTED_BLINK_INTERVAL_MS = 120;
constexpr uint32_t LIGHT_FADE_DURATION_MS = 1200;

LightPayload current{};
uint32_t lastCoordinatorRx = 0;
uint32_t heartbeatTimeoutMs = DEFAULT_HEARTBEAT_TIMEOUT_MS;
uint32_t lastLedToggle = 0;
bool statusLedOn = false;
uint8_t brightness[10]{};
uint8_t fadeStart[10]{};
uint8_t fadeTarget[10]{};
uint8_t pwmAccumulator[10]{};
uint32_t fadeStartedAt = 0;
bool fadeActive = false;

uint8_t outputPin(int index) {
  if (index == 0) return FIRST_STAR_PIN;
  if (index == 1) return STARS_PIN;
  return CONSTELLATION_PINS[index - 2];
}

bool outputActiveHigh(int index) {
  if (index == 0) return FIRST_STAR_ACTIVE_HIGH;
  if (index == 1) return STARS_ACTIVE_HIGH;
  return CONSTELLATIONS_ACTIVE_HIGH;
}

bool requestedOutput(int index, const LightPayload &value) {
  if (index == 0) return value.firstStar;
  if (index == 1) return value.stars;
  return value.patterns & (1 << (index - 2));
}

void setOutput(uint8_t pin, bool on, bool activeHigh) {
  digitalWrite(pin, (on == activeHigh) ? HIGH : LOW);
}

void applyLightOutputs() {
  for (int index = 0; index < 10; ++index) {
    brightness[index] = requestedOutput(index, current) ? 255 : 0;
    fadeTarget[index] = brightness[index];
    setOutput(outputPin(index), brightness[index] != 0,
              outputActiveHigh(index));
  }
  fadeActive = false;
}

void sendAcknowledgement(uint32_t sequence) {
  AckPayload acknowledgement{};
  acknowledgement.h =
      header(Type::LIGHT_ACK, sizeof(acknowledgement), sequence);
  acknowledgement.applied = 1;
  acknowledgement.firstStar = current.firstStar;
  acknowledgement.stars = current.stars;
  acknowledgement.patterns = current.patterns;
  acknowledgement.uptimeMs = millis();

  esp_now_send(MAC_COORD,
               reinterpret_cast<uint8_t *>(&acknowledgement),
               sizeof(acknowledgement));
}

void beginLightTransition(bool useFade) {
  if (!useFade) {
    applyLightOutputs();
    return;
  }
  for (int index = 0; index < 10; ++index) {
    fadeStart[index] = brightness[index];
    fadeTarget[index] = requestedOutput(index, current) ? 255 : 0;
  }
  fadeStartedAt = millis();
  fadeActive = true;
}

void updateLightFade(uint32_t now) {
  if (fadeActive) {
    float progress = min(1.0f, (now - fadeStartedAt) /
                                   static_cast<float>(LIGHT_FADE_DURATION_MS));
    // Smoothstep avoids an abrupt start/end; gamma gives a natural visual fade.
    float smooth = progress * progress * (3.0f - 2.0f * progress);
    float shaped = powf(smooth, 1.8f);
    for (int index = 0; index < 10; ++index) {
      brightness[index] = lroundf(fadeStart[index] +
          (fadeTarget[index] - fadeStart[index]) * shaped);
    }
    if (progress >= 1.0f) fadeActive = false;
  }
  // 1 kHz pulse-density modulation supports all ten outputs on ESP32-C3,
  // whose hardware LEDC channel count is smaller than the output count.
  for (int index = 0; index < 10; ++index) {
    uint16_t sum = pwmAccumulator[index] + brightness[index];
    pwmAccumulator[index] = static_cast<uint8_t>(sum);
    setOutput(outputPin(index), sum > 255, outputActiveHigh(index));
  }
}

void receiveEspNow(const uint8_t *, const uint8_t *data, int length) {
  if (length != static_cast<int>(sizeof(LightPayload))) {
    return;
  }

  LightPayload received{};
  memcpy(&received, data, sizeof(received));

  if (!valid(received.h, length) || received.h.type != Type::LIGHT_SET) {
    return;
  }

  current = received;
  lastCoordinatorRx = millis();
  heartbeatTimeoutMs =
      max(MIN_HEARTBEAT_TIMEOUT_MS, received.heartbeatTimeoutMs);

  beginLightTransition(received.fade != 0);
  sendAcknowledgement(received.h.seq);

  Serial.printf(
      "LIGHT seq=%lu first=%u stars=%u constellations=0x%02X "
      "timeout=%lu ms\n",
      received.h.seq,
      current.firstStar,
      current.stars,
      current.patterns,
      heartbeatTimeoutMs);
}

void setup() {
  Serial.begin(115200);

  pinMode(FIRST_STAR_PIN, OUTPUT);
  pinMode(STARS_PIN, OUTPUT);
  pinMode(STATUS_LED_PIN, OUTPUT);
  for (uint8_t pin : CONSTELLATION_PINS) {
    pinMode(pin, OUTPUT);
  }

  applyLightOutputs();
  digitalWrite(STATUS_LED_PIN, LOW);

  WiFi.mode(WIFI_STA);
  esp_wifi_set_mac(WIFI_IF_STA, MAC_LIGHT);
  esp_wifi_set_channel(CHANNEL, WIFI_SECOND_CHAN_NONE);

  esp_now_init();
  esp_now_register_recv_cb(receiveEspNow);

  esp_now_peer_info_t coordinatorPeer{};
  memcpy(coordinatorPeer.peer_addr, MAC_COORD, sizeof(MAC_COORD));
  coordinatorPeer.channel = CHANNEL;
  esp_now_add_peer(&coordinatorPeer);

  Serial.println("LIGHT READY");
}

void loop() {
  const uint32_t now = millis();
  const bool connected =
      lastCoordinatorRx != 0 &&
      now - lastCoordinatorRx <= heartbeatTimeoutMs;
  updateLightFade(now);
  const uint32_t blinkInterval = connected ? CONNECTED_BLINK_INTERVAL_MS
                                           : DISCONNECTED_BLINK_INTERVAL_MS;
  if (now - lastLedToggle >= blinkInterval) {
    lastLedToggle = now;
    statusLedOn = !statusLedOn;
    digitalWrite(STATUS_LED_PIN, statusLedOn ? HIGH : LOW);
  }

  delay(1);
}

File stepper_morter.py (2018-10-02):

import time
import RPi.GPIO as GPIO


H = GPIO.HIGH
L = GPIO.LOW

# 4, 17, 27, 22

class StepperMotor:
    def __init__(self, pMode, p1, p2, p3, p4, t):
        self.pMode = pMode
        self.p1 = p1
        self.p2 = p2
        self.p3 = p3
        self.p4 = p4
        self.t = t


    def setInterval(self, t):
        self.t = t
        
    
    def __enter__(self):
        GPIO.setmode(self.pMode)
        GPIO.setup(self.p1, GPIO.OUT)
        GPIO.setup(self.p2, GPIO.OUT)
        GPIO.setup(self.p3, GPIO.OUT)
        GPIO.setup(self.p4, GPIO.OUT)

    
    def __exit__(self):
        GPIO.cleanup
    

    def rRotate(self, step, t):
        for i in range(step):
            GPIO.output(self.p1, H)
            GPIO.output(self.p2, L)
            GPIO.output(self.p3, L)
            GPIO.output(self.p4, H)
            time.sleep(self.t)

            GPIO.output(self.p1, L)
            GPIO.output(self.p2, L)
            GPIO.output(self.p3, H)
            GPIO.output(self.p4, H)
            time.sleep(self.t)

            GPIO.output(self.p1, L)
            GPIO.output(self.p2, H)
            GPIO.output(self.p3, H)
            GPIO.output(self.p4, L)
            time.sleep(self.t)

            GPIO.output(self.p1, H)
            GPIO.output(self.p2, H)
            GPIO.output(self.p3, L)
            GPIO.output(self.p4, L)
            time.sleep(self.t)


    def fRotate(self, step, t):
        for i in range(step):
            GPIO.output(self.p1, H)
            GPIO.output(self.p2, H)
            GPIO.output(self.p3, L)
            GPIO.output(self.p4, L)
            time.sleep(self.t)

            GPIO.output(self.p1, L)
            GPIO.output(self.p2, H)
            GPIO.output(self.p3, H)
            GPIO.output(self.p4, L)
            time.sleep(self.t)

            GPIO.output(self.p1, L)
            GPIO.output(self.p2, L)
            GPIO.output(self.p3, H)
            GPIO.output(self.p4, H)
            time.sleep(self.t)

            GPIO.output(self.p1, H)
            GPIO.output(self.p2, L)
            GPIO.output(self.p3, L)
            GPIO.output(self.p4, H)
            time.sleep(self.t)

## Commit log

2018-10-02 classing stepper morter
2018-10-05 fix motor entering
2018-10-05 stepper server
2018-10-05 de morgan
2019-10-07 モーターの速度を変えるために汚いコードになってます
2024-05-04 change: ピンアサ変更 .wav追加
2024-05-11 change: ピンアサ変更
2024-05-11 chore: 不要なファイルの削除
2024-05-16 chore: pwm.py削除
2024-05-19 autorun内のパスを相対パスに変更
2024-05-20 chore: memo追加
2024-05-27 update: switch.py StepperMotor.py に実行時オプションを追加
2024-06-02 memoにピン番号の情報を追加
2024-06-06 chore: ディレクトリ構成を変更
2024-06-06 chore: storybook追加
2024-06-06 add: UI一旦完成
2024-06-10 add: ledの状態管理(開発途中)
2024-06-12 change : ファイルを分割 & add: LEDs.json追加
2024-06-14 add: socket.ioテスト
2024-06-15 chore: ファイル名変更(autoModeManage)
2024-06-16 change: ledManage(旧ledList)を変更
2024-06-16 add: apiをGPIOの操作以外の部分だけ作成
2024-06-16 chore: Homeをhomeに改名
2024-06-16 chore: route削除
2024-06-16 add: apiServerLED追加
2024-06-16 change: apiServerLEDがleds.jsonを参照するよう変更
2024-06-17 add: apiServerMotor追加
2024-06-19 update: motorApi回転の上書きを可能にした
2024-06-19 add: webページからapiRequestするように追加
2024-06-19 chore: border変更&host名変更
2024-06-20 add: automode用api実装
2024-06-20 chore: README.md追加
2024-06-20 update: 中断ができるように改良
2024-06-20 add: console出力
2024-06-20 add: console出力に色付けた&interval="end"に対応
2024-06-21 chore: logに色付け autoModeを複数関数に分割
2024-06-21 change: motorをsubprocessを使った実装に変更
2024-06-23 add: httpリクエストのlogを追加
2024-06-23 add: automode停止追加
2024-06-24 add: CORS許可
2024-06-24 change: 回転速度選択のUIを変更
2024-06-24 add: 回転停止ボタンを追加
2024-06-24 UIを変更
2024-06-28 add: trpcを使用可能に
2024-07-10 恒星のon/offを調整
2024-07-10 eslintが通るように変更
2024-09-05 add: memo追加
2024-09-22 change: ホスト名を変更
2024-09-22 update: モタドラに対応
2024-10-13 chore: コミットしてなかったファイル（回路図など）を追加
    [ittose.kicad_pcb, ittose.kicad_sch, kousei.kicad_pcb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]
2024-10-28 add: .env追加
2025-07-21 去年commitしてなかったもの(pi-controller実機との差分)
2025-07-21 前のcommitと同様
2025-07-21 change: pin配置変更 uartのpinと被ってたため 全く動作確認をしてない(多分動かない)
2025-07-21 change: 直前のコミットに追加修正
2025-07-21 chore: ファイル整理
2025-08-31 add: ドキュメントを追加
    [pinout.xlsx]
2025-11-06 change: LEDにfade機能を追加
2025-11-06 2025年工大祭のpi-controllerの差分
2025-11-06 add: 一等星基板
    [ittose.kicad_pcb, ittose.kicad_sch]
2026-01-25 add: 星座・一等星基板
    [seiza_ittose.kicad_pcb, seiza_ittose.kicad_sch]
2026-02-02 add: 恒星、一等星、星座基板を新調
    [ittose.kicad_pcb, ittose.kicad_sch, kousei.kicad_pcb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]
2026-02-21 add: モタドラ完成
    [motor_driver.kicad_pcb, motor_driver.kicad_sch]
2026-02-21 change: LED追加, EN->nEN
    [kousei_v2.kicad_pcb, kousei_v2.kicad_sch, seiza_ittose.kicad_pcb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]
2026-03-28 fix:PMOSのDとS間違えてた
    [motor_driver.kicad_pcb, motor_driver.kicad_sch]
2026-10-10 Fix motor gearing and add acceleration ramp
2026-10-10 Add 20261010-6 planetarium release with motor positioning and fade fixes
